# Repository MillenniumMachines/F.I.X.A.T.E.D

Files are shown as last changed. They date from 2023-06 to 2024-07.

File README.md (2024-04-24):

# millenium machines F.I.X.A.T.E.D

Welcome to the Millenium machines fixated project. Fixated is a list of fixtures and parts created for the Milo line of machines.

## FIXATED fixture plates  

- The FIXATED full monty

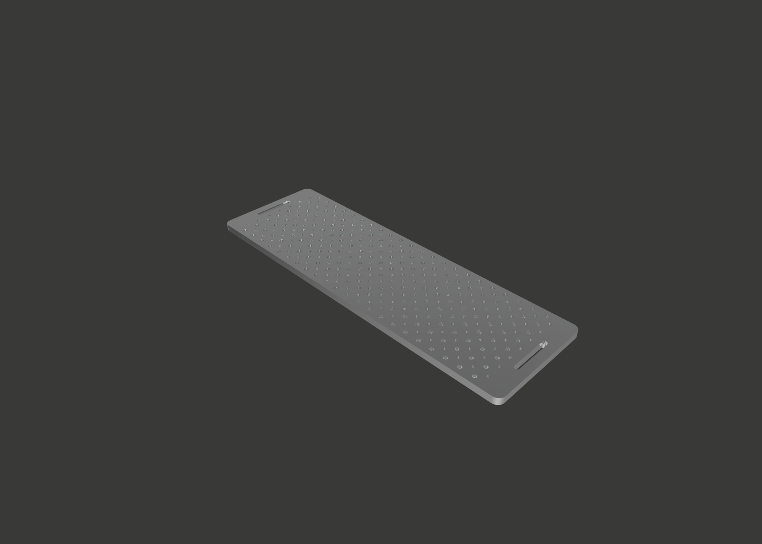
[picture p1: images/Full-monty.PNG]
The FIXATED full monty


A fixture plate system designed to fit the bed of a standard sized milo V1.5 (500x160mm) and features 
hole spacings of 20mm on center intended for tapping to M5 and another set of holes also 20mm on center to accomadate M6 dowels.

- The FIXATED full monty (SLIM)

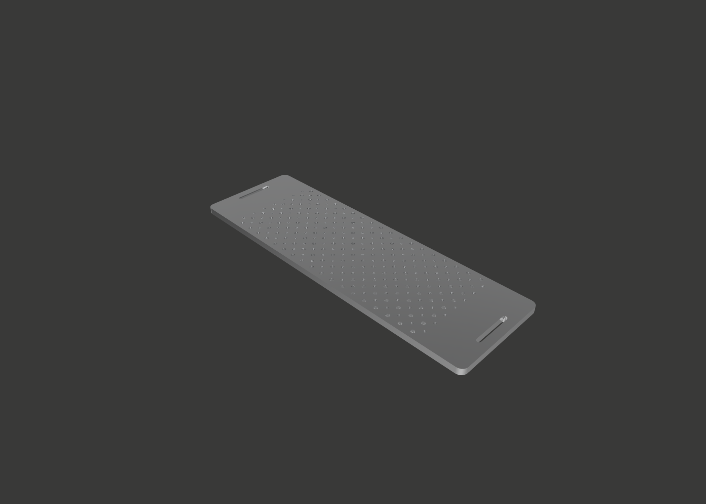
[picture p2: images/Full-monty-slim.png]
The FIXATED full monty slim


The full monty slim covers the same features as the regular full monty but only covers the workable area of a standard milo v1.5.

- The FIXATED continental breakfast 

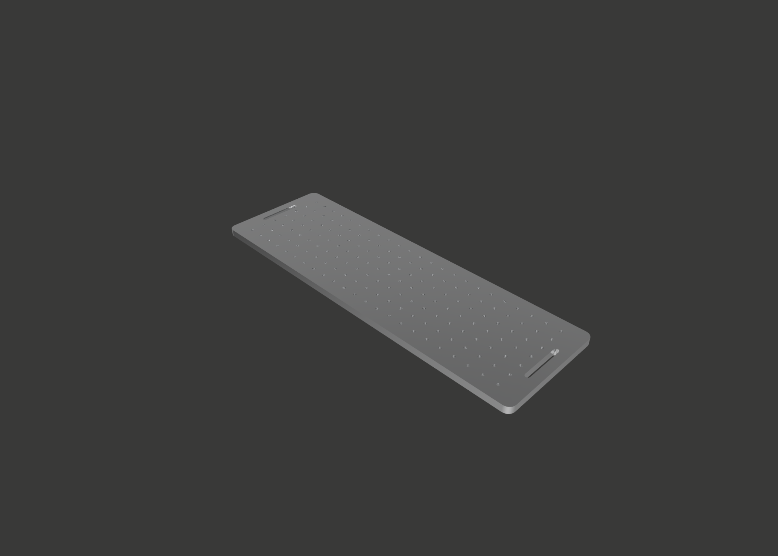
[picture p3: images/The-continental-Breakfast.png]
The FIXATED Continental breakfast


The full monty's slim european cousin this fixture plate system designed to fit the bed of a standard sized milo V1.5 (500x160mm) and features hole spacings of 20mm on center intended for tapping to M5 unlike the full monty it does not include the holes for the M6 dowels.

- The FIXATED continental breakfast (SLIM)

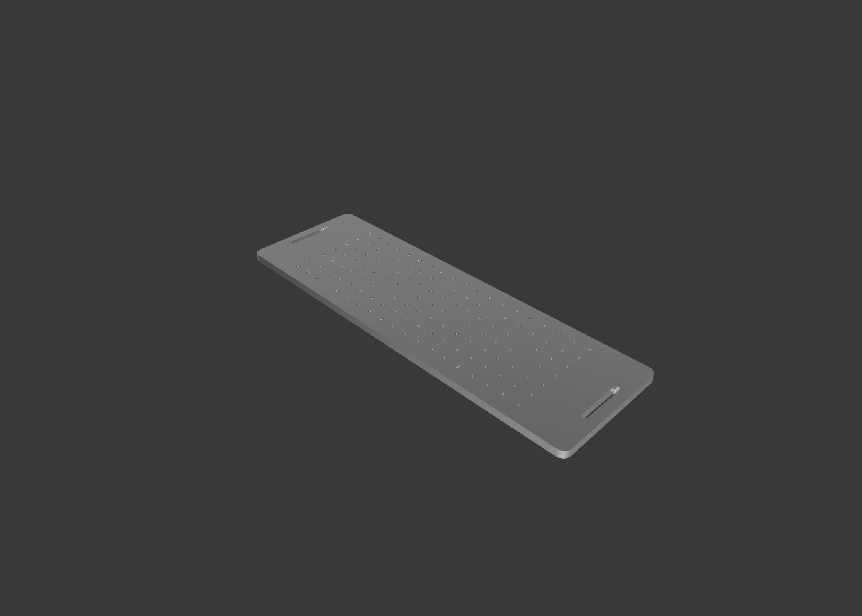
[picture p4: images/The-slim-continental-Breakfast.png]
The FIXATED Continental breakfast


The continental breakfast slim covers the same features as the regular continental breakfast but only covers the workable area of a standard milo v1.5.

For manufacturing specifications and technical drawings please see [documentation](docs/README.md).

## FIXATED Plate Clamps

The optimal way to hold your fixated plate down is to utilise these plate clamps. They can be 3d printed but for the best performance you will want to machine a set.

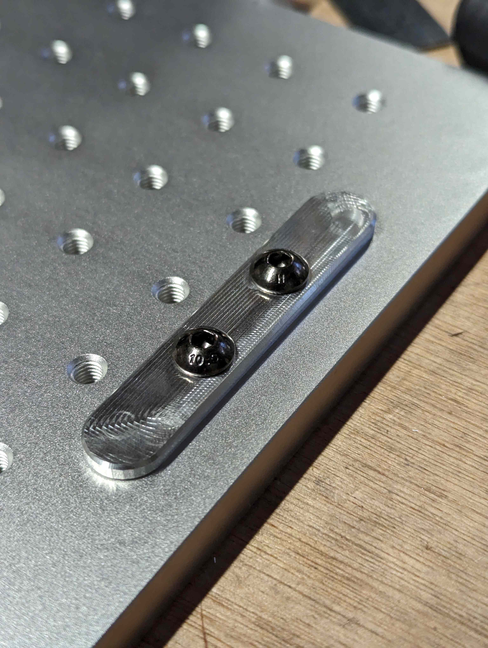
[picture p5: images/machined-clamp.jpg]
FIXATED machined plate clamp


For manufacturing specifications and technical drawings please see [documentation](/docs/Machined%20plate%20clamps/README.md).

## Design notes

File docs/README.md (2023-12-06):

# millenium machines F.I.X.A.T.E.D documetation 

Welcome to fixated Docs here you'll find documentation related to the manufacture and technical specifications of all our fixtures, these specifications are only a guideline and can be modified to meet your requirements.  

##  DOCUMENTATION

### - All Fixated fixture plates 

MATERIAL           : Cast tooling plate, MIC6 or aluminium 6061/6068 that has been milled flat

PROCESS            : Laser Cut Or CNC milled 

GENERAL TOLERANCES FOR PRE-TAPPED AND PRE-REAMED PARTS: 

                     - Standard fit tolerances for all 4.2mm holes to be tapped later to M5

                     - Standard fit tolerances for all 5.8mm holes to be reamed later to M6 (full monty only)
                     
                     - Perimeter tolerance of -0.05mm +0mm 
                     
                     - Perimeter parralelism tolerance of 0.05mm acrross the 2 longest sides
                     
                     - No given tolerance for parralelism of top and bottom faces
                     
                     - Flatness tolerance of top and bottom 0.05mm across length and width of part
                   
NOTES: These plates are intended to be laser cut or milled as blanks, all holes have been sized to tapped and reamed by the end user to reduce costs. Full monty and full monty slim may cause issues with material stress release during manufacture which can lead to part warping if you do not need the use of the M6 dowel feature consider using the continental breakfast variants instead. If you require the tolerances for a tapped and reamed plate you can find the tolerances below.

GENERAL TOLERANCES FOR TAPPED AND REAMED PARTS: 

                     - M5 threaded holes (H6)

                     - M6 Dowel holes (H7) (full monty only)
                     
                     - Perimeter tolerance of -0.05mm +0mm 
                     
                     - Perimeter parralelism tolerance of 0.05mm acrross the 2 longest sides
                     
                     - No given tolerance for parralelism of top and bottom faces
                     
                     - Flatness tolerance of top and bottom 0.05mm across length and width of part

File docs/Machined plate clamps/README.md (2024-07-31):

# Millennium Machines F.I.X.A.T.E.D Machined Plate Clamps Documentation 

This page contains the information required to machine your own FIXATED plate clamps. This is considered an ideal first project as it utilises low cost small pieces of stock material, a few simple setups and only 3 different end mills.

##  DOCUMENTATION

CAD :
- [STEP file](/CAD/Fixture%20Plates/Machined%20plate%20clamps/Fixated%20clamp.step)
- [f3d file including CAM operations](/CAD/Fixture%20Plates/Machined%20plate%20clamps/Fixated%20clamp.f3d)
- [Fusion tool library](/CAD/Fixture%20Plates/Machined%20plate%20clamps/Fixated%20clamp%20LDO%20tool%20library.tools)

MATERIAL           : Bar stock, aluminium 6061/6068

BOM                :                

- 2x 20x15x70mm Aluminium 6082T6 Flat Bar
- 4x M5 x 10mm Form A Flat Washers (DIN 125) - Stainless Steel (A2)
- 4x M5 x 18mm Socket Button Screws (ISO 7380-1) - Stainless Steel (A2)
- 4x Roll in Spring Loaded T Nut M5 for 20x20 20 Series Aluminium Extrusions

Tooling :

- End Mill, Single Flute, 6x22mm, Carbide, DLC Coating
- End Mill, Single Flute, 3x12mm, Carbide, DLC Coating
- Chamfer Mill, Three Flute, 90°, 6mm, Carbide, DLC Coating

PROCESS            : Milled on Milo 

RESOURCES          : 

- [Setup sheet 1](/docs/Machined%20plate%20clamps/Fixated%20clamp%20setup%201.pdf)
- [Setup sheet 2](/docs/Machined%20plate%20clamps/Fixated%20clamp%20setup%202.pdf)
- [Setup sheet 3](/docs/Machined%20plate%20clamps/Fixated%20clamp%20setup%203.pdf)
- [video guide by 3DPandME](https://www.youtube.com/live/bzlwI8ah9Cs?si=_gUOolzj2h1DFucY)

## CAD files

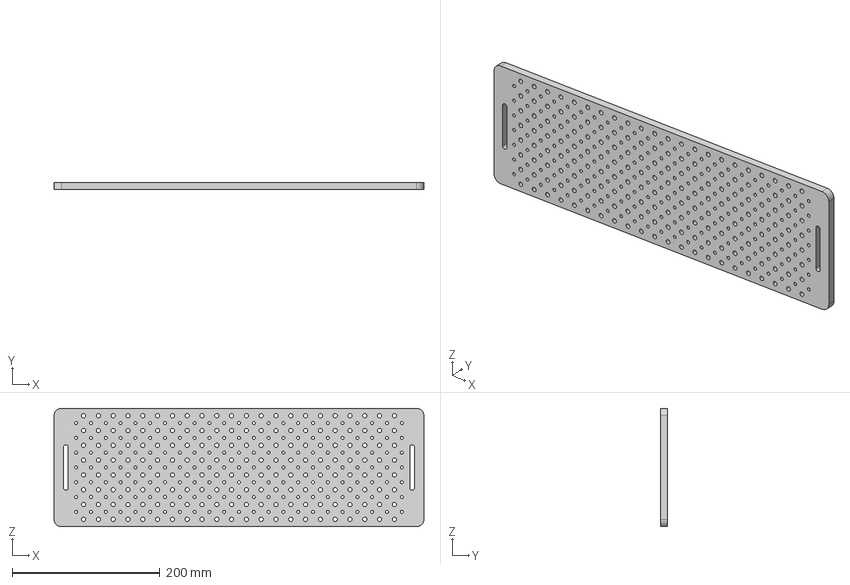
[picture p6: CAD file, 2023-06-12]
CAD/Fixture Plates/The Full monty/Full-Monty-Fixture-Plate.step
500.0 x 10.0 x 160.0 mm

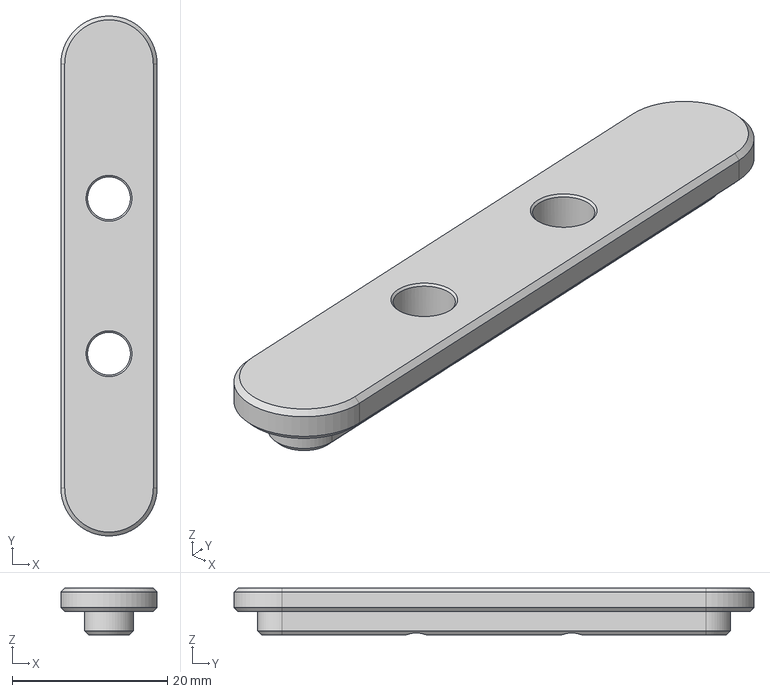
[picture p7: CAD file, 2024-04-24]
CAD/Fixture Plates/Machined plate clamps/Fixated clamp.step
12.4 x 66.9 x 6.00 mm

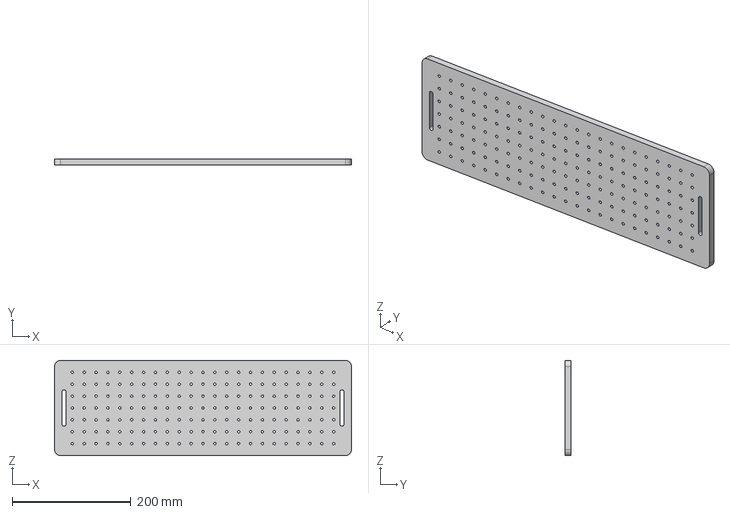
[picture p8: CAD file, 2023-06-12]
CAD/Fixture Plates/The continental breakfast/The-continental-Breakfast.step
500.0 x 10.0 x 160.0 mm

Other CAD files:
CAD/Fixture Plates/The Full monty/Full-Monty-slim-fixture-plate.step
CAD/Fixture Plates/The continental breakfast/The-slim-continental-Breakfast.step
CAD/Fixture Plates/Machined plate clamps/Fixated clamp.f3d

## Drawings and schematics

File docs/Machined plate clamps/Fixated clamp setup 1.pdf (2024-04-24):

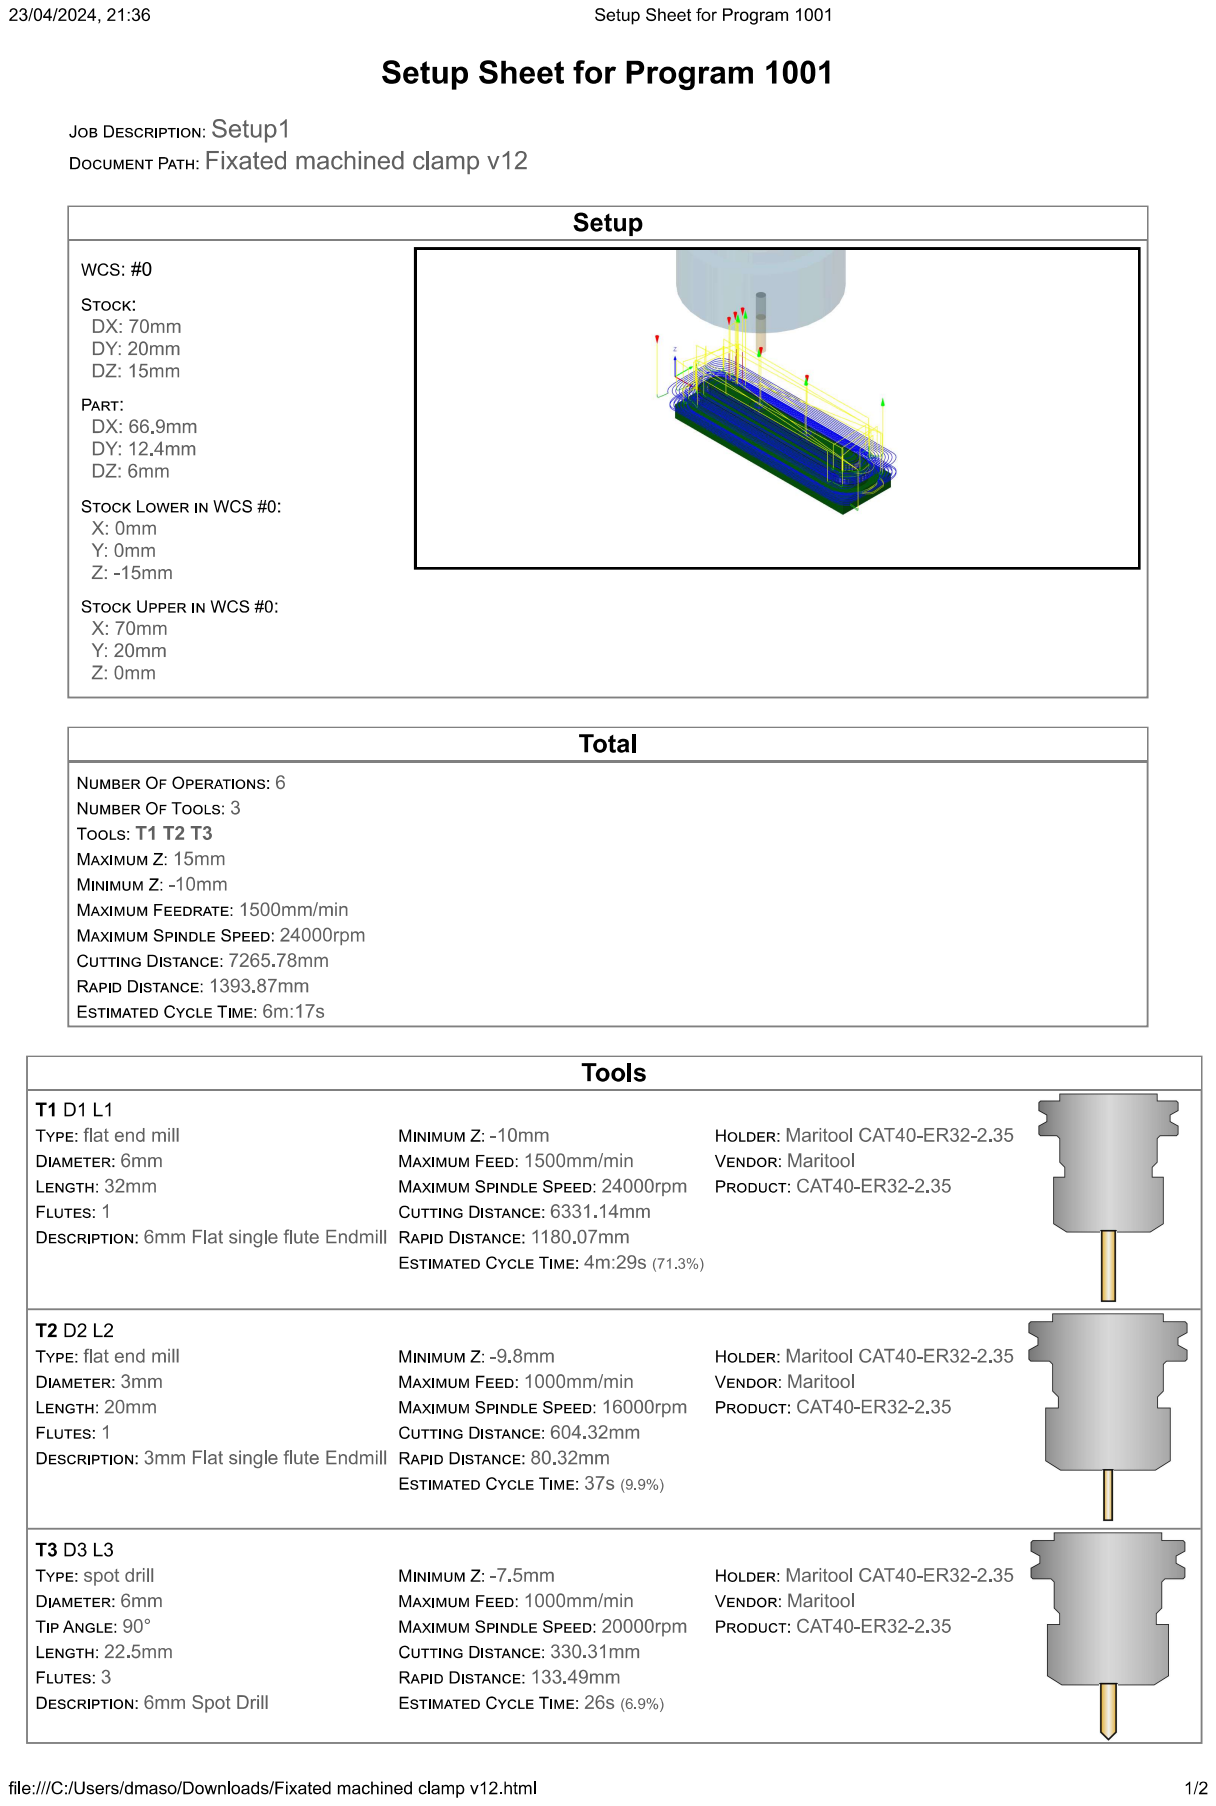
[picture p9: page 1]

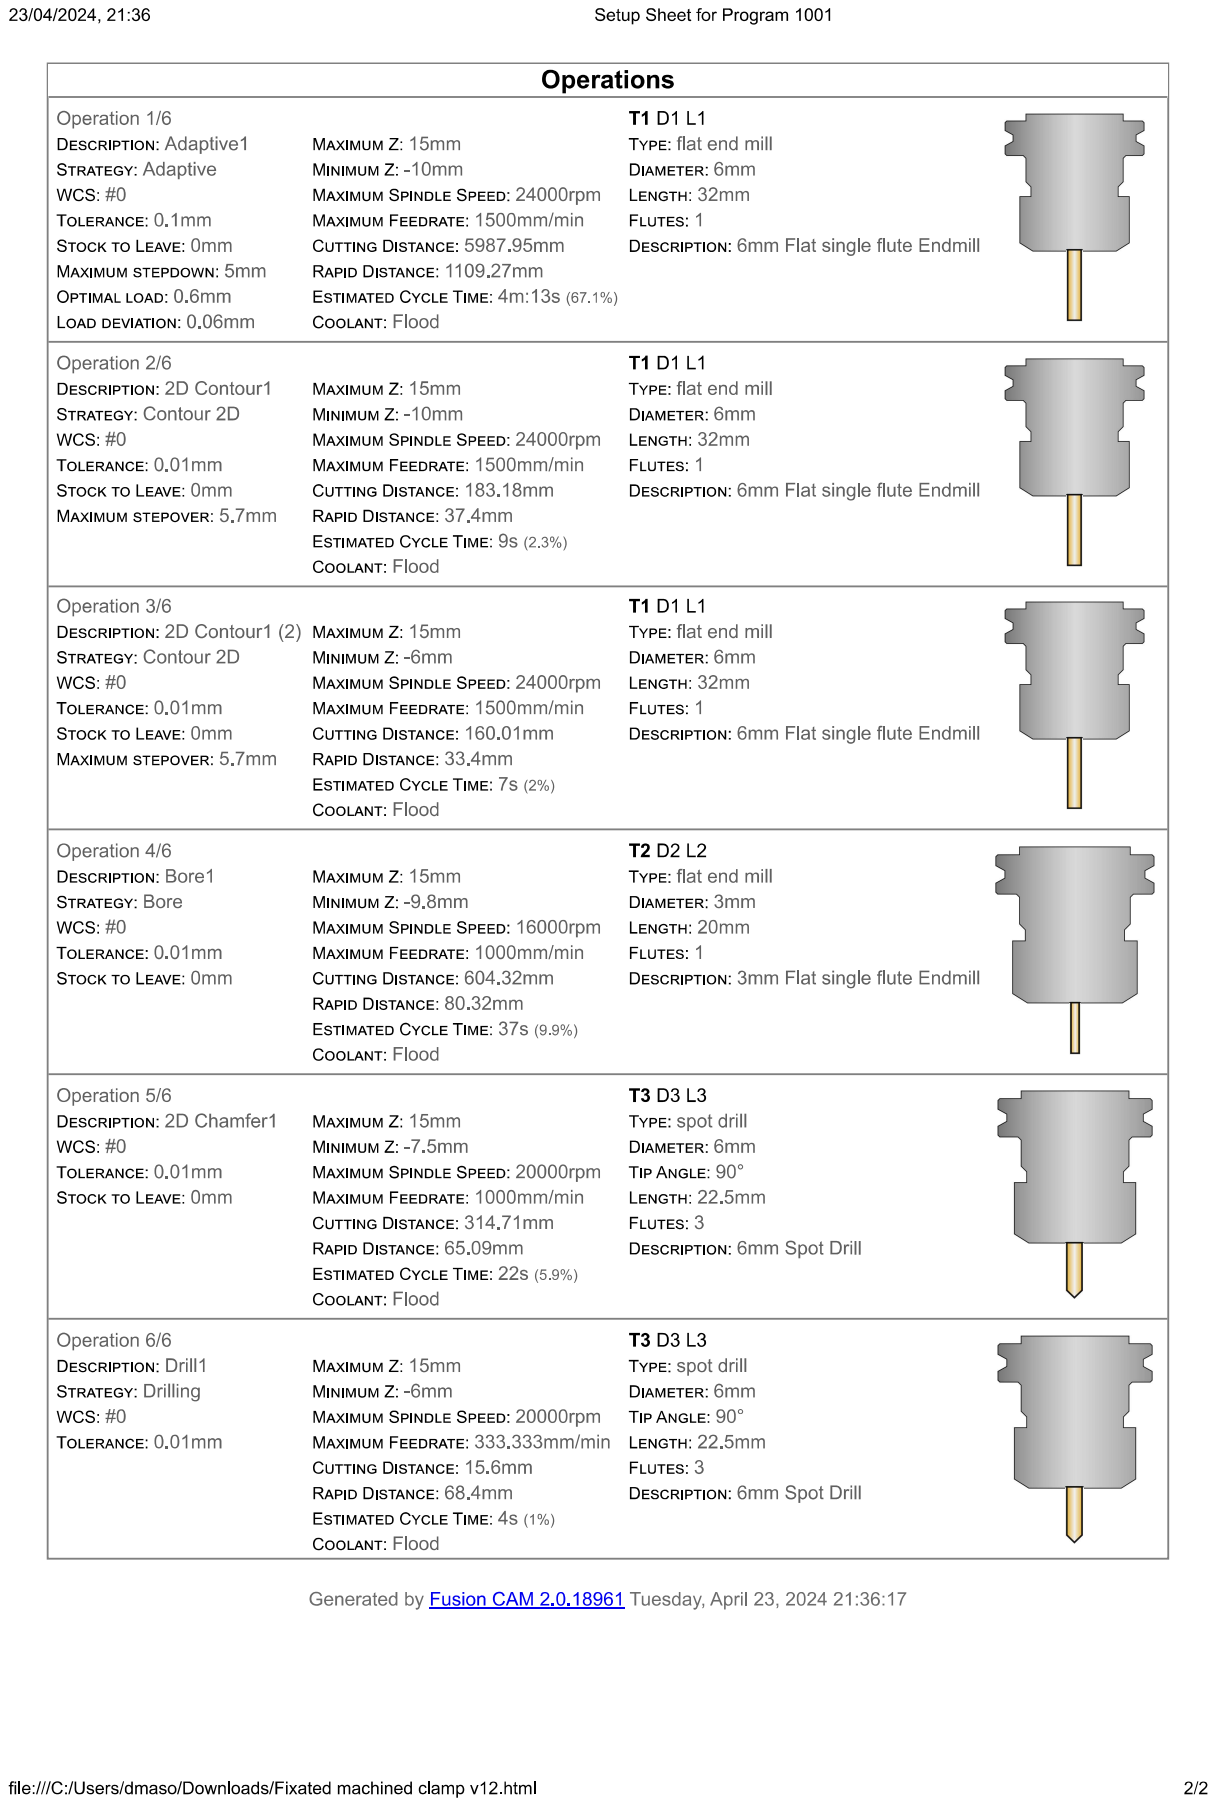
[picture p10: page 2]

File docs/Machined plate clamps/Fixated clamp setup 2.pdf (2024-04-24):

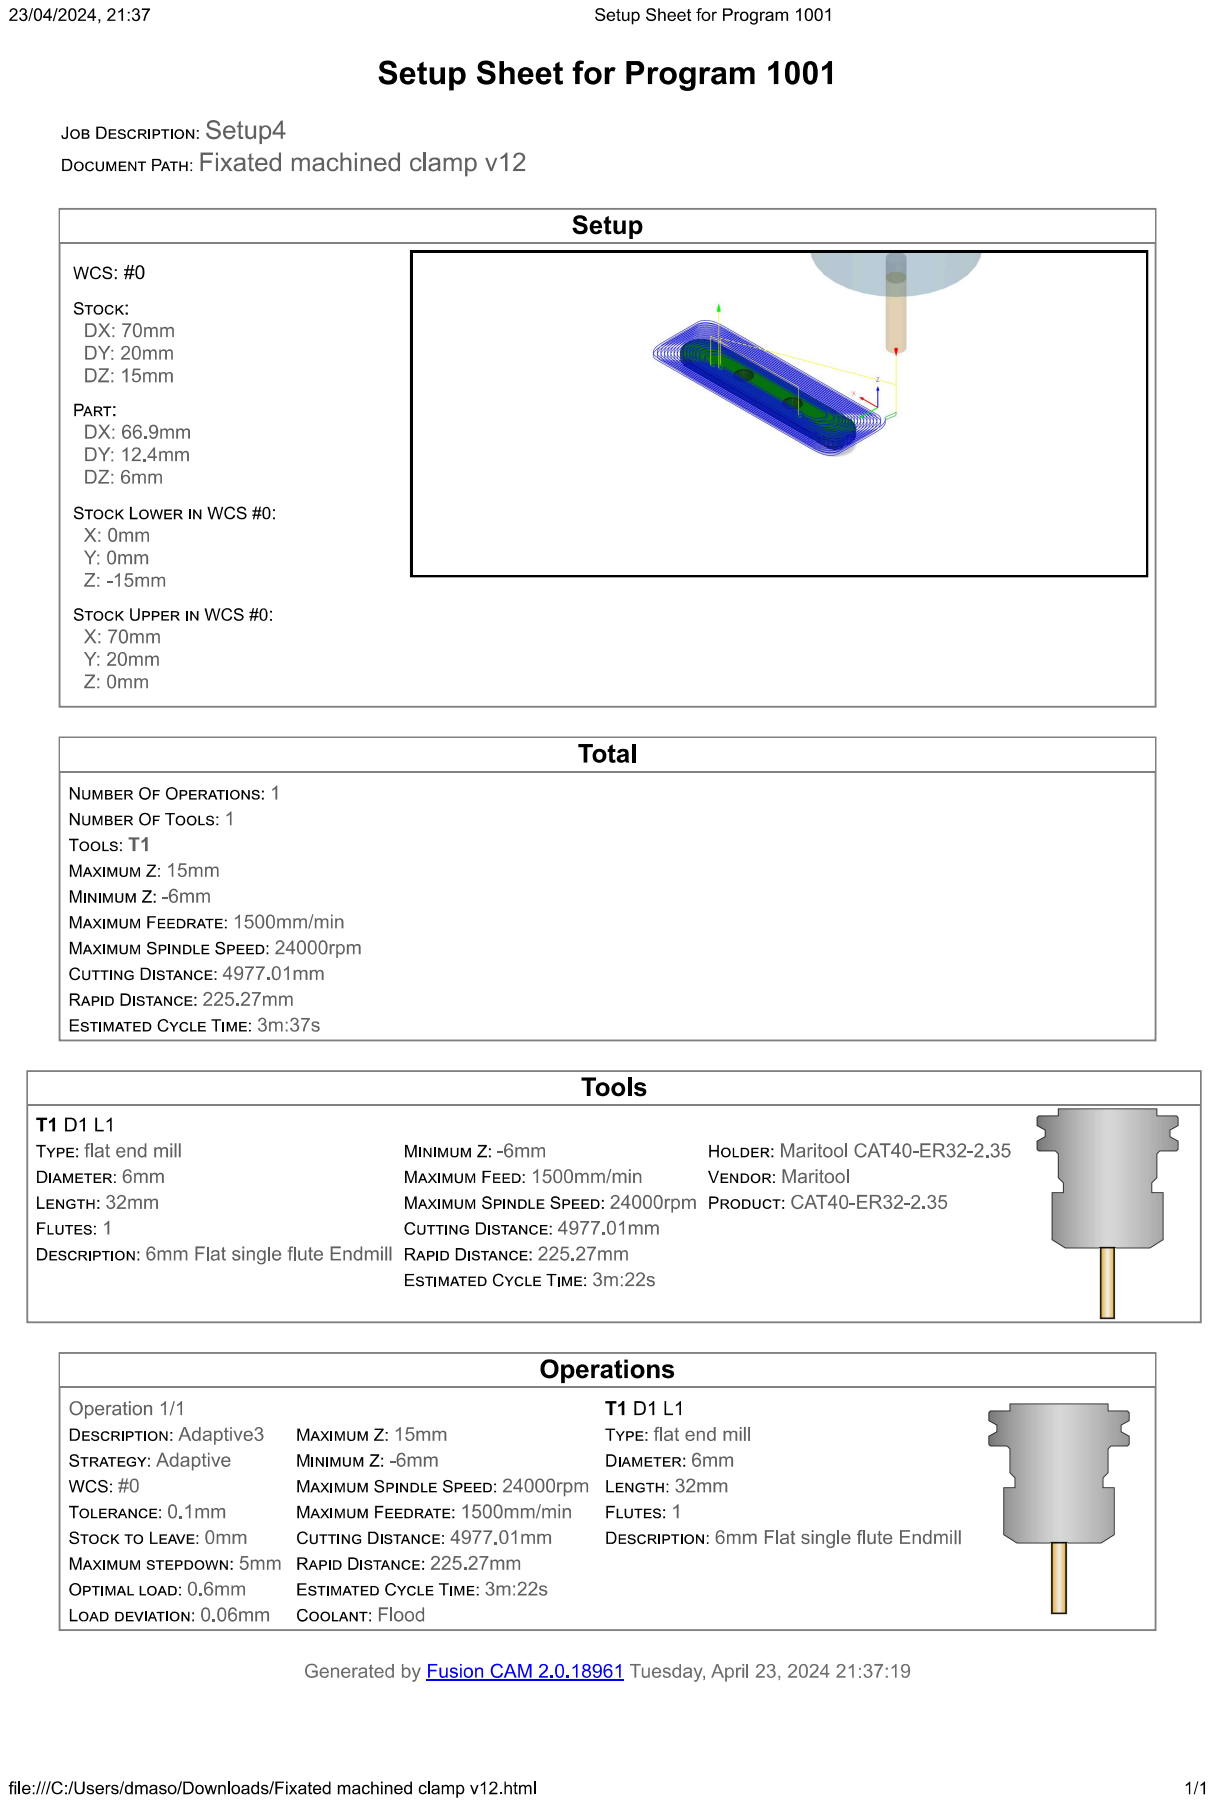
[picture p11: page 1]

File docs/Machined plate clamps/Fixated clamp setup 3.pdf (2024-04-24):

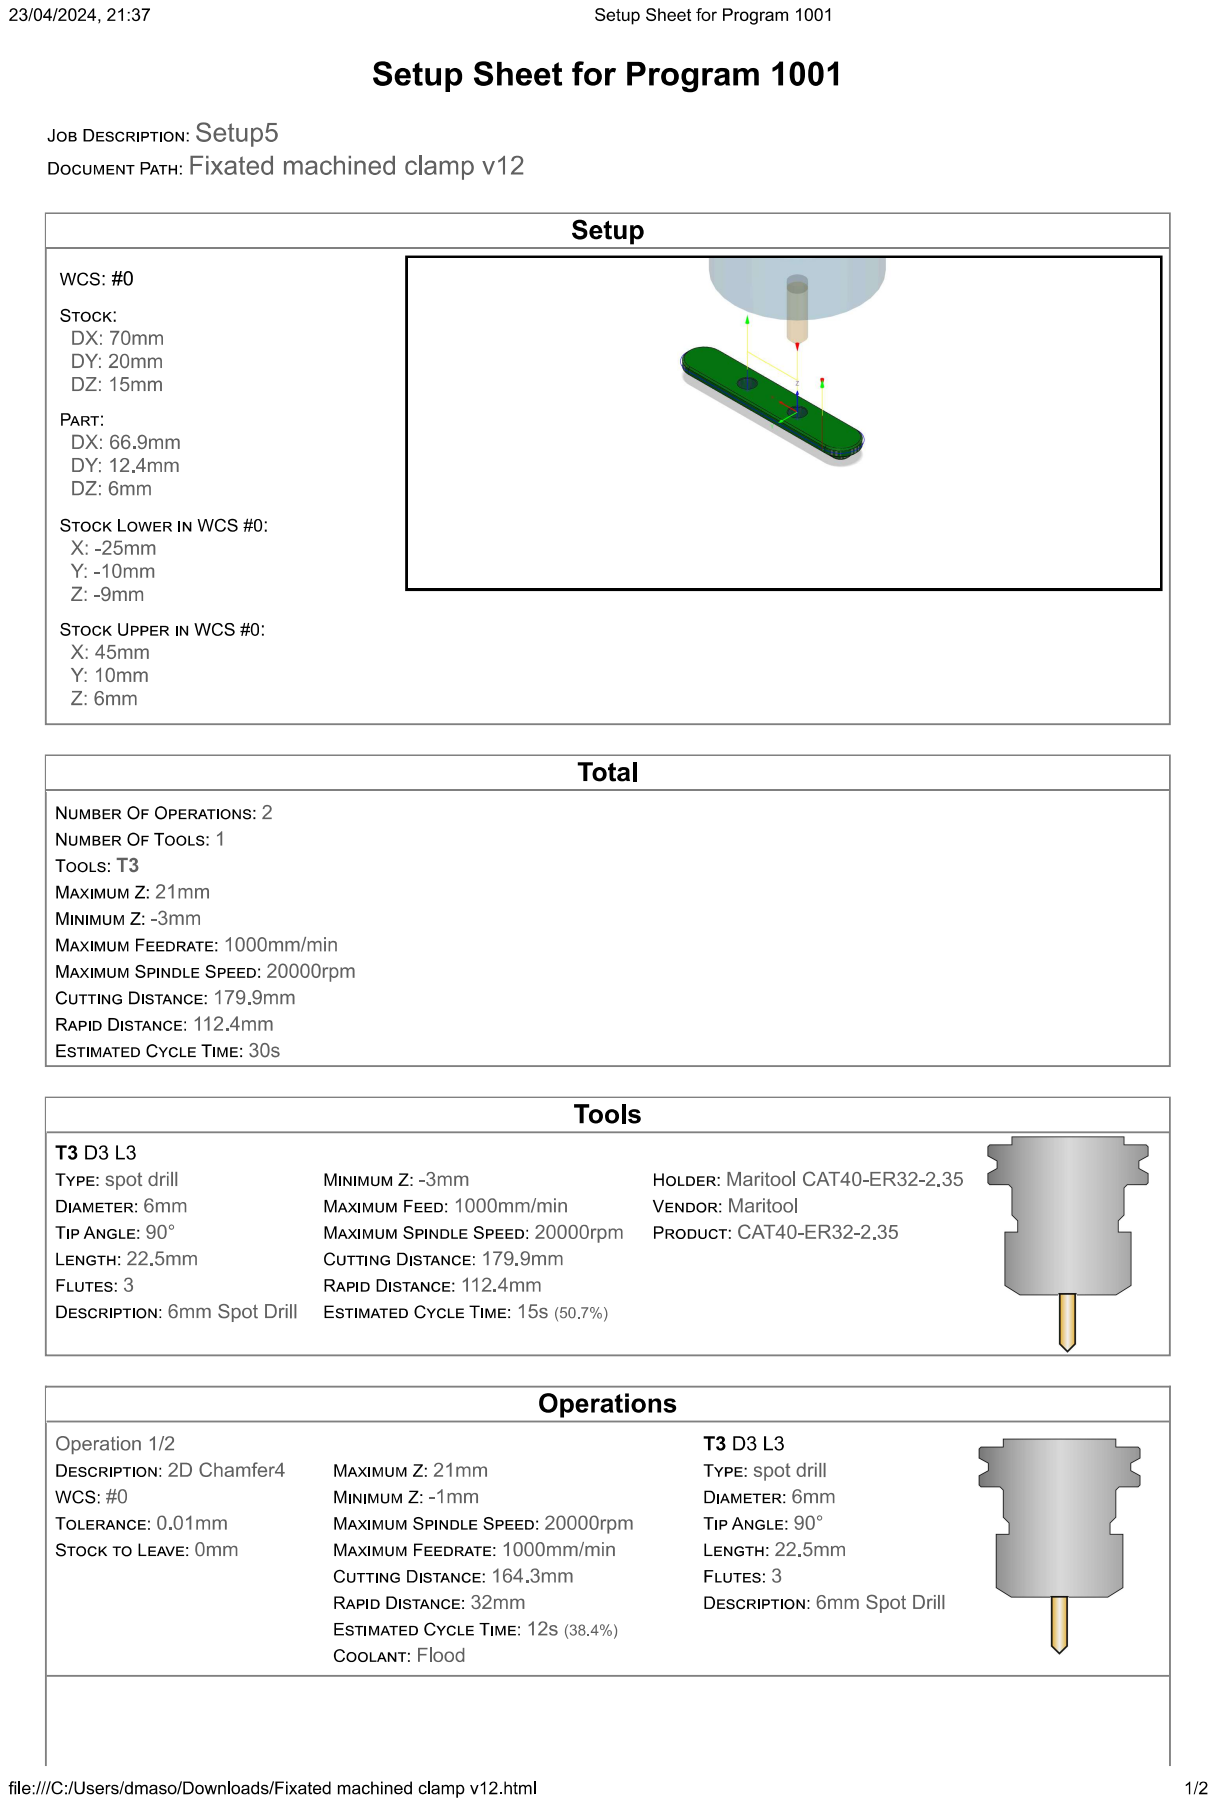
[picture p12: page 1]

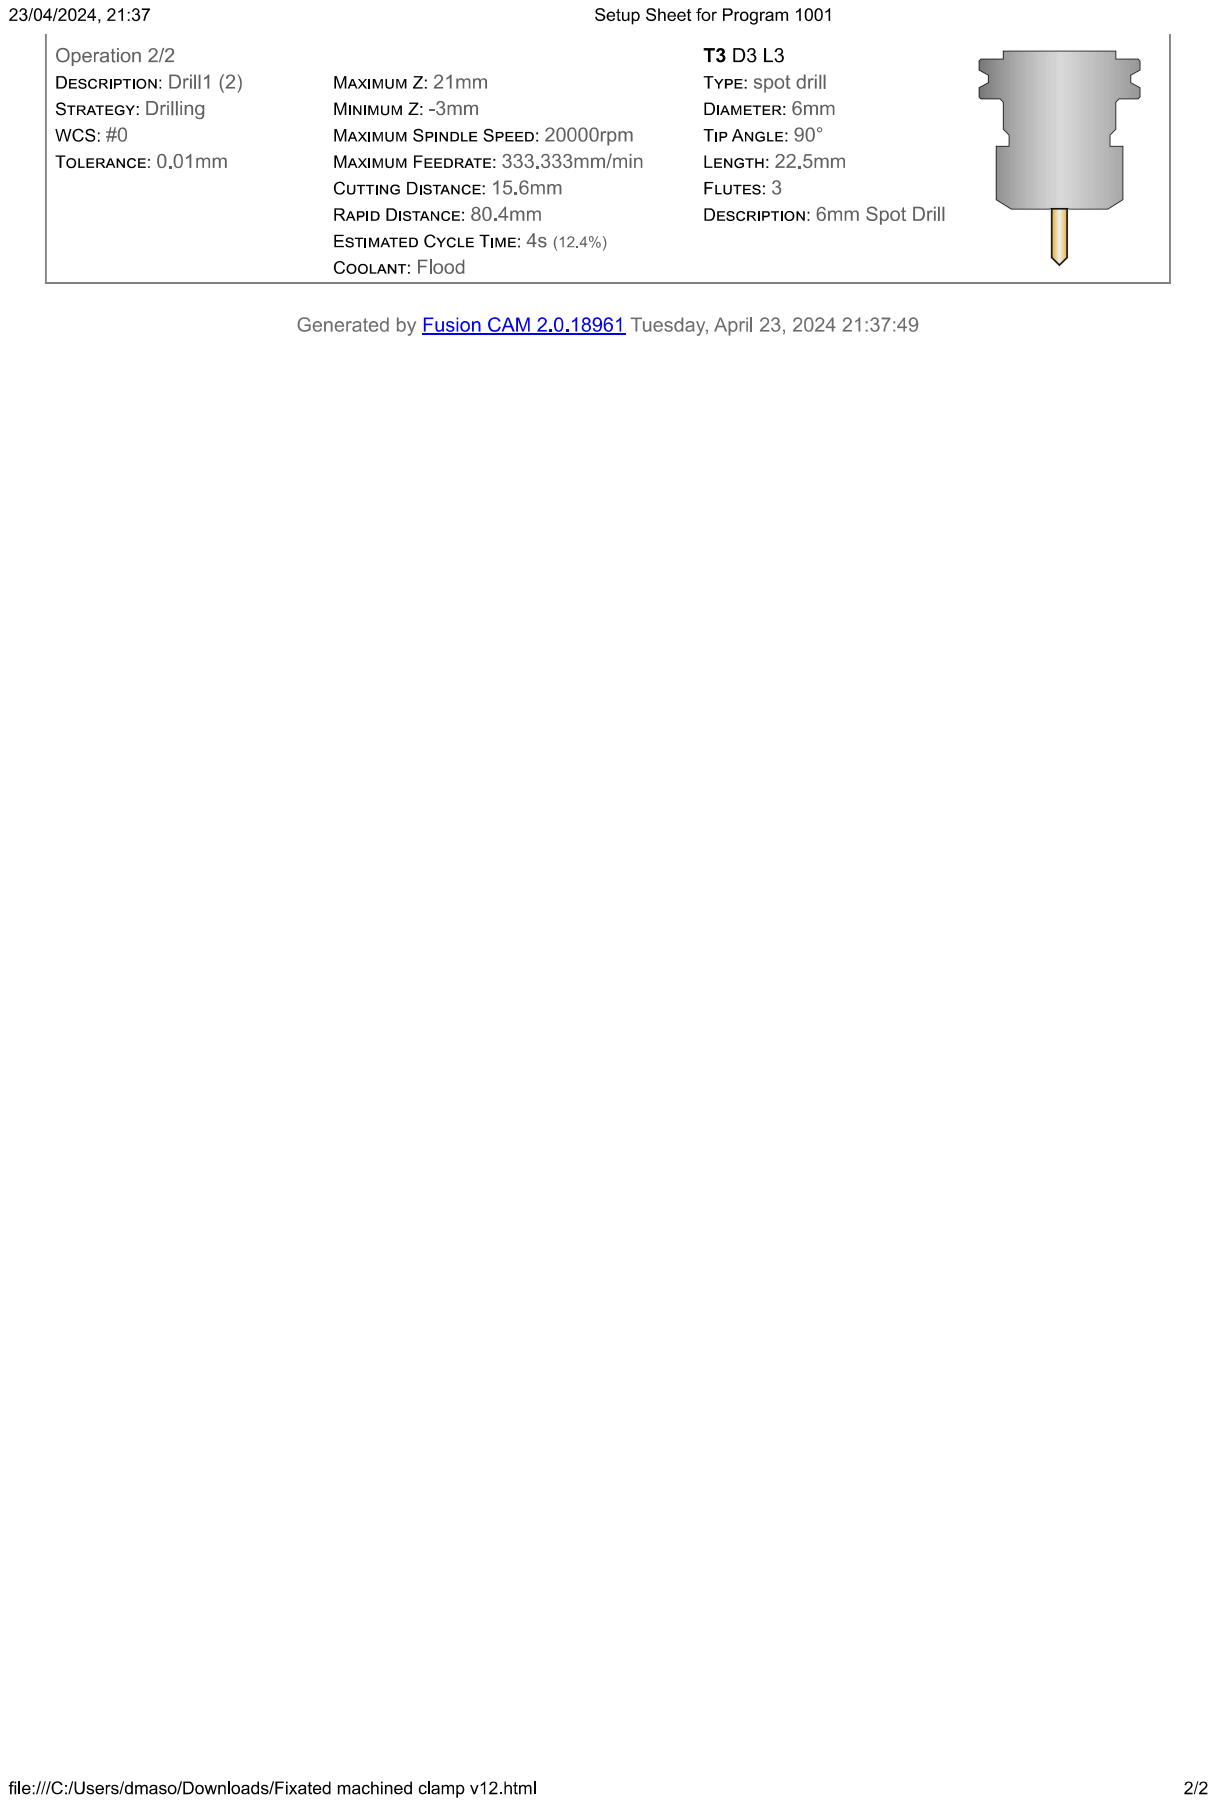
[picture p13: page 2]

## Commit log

2023-06-12 Added fixture plate CAD
    [Full-Monty-Fixture-Plate v2.step, Full-Monty-slim-fixture-plate v1.step, The-continental-Breakfast v1.step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]
2023-06-12 Added images of fixture plates
2023-06-12 Added fixture plate .svg files
2023-11-24 Consistent renaming to match other repos
    The usual changes:
    - Capitalisation, spacing, removing redundancy
    - Changed formatting of readme and docs for consistency
    - Modified 'M6 dowels' to '6mm dowels'
    [Full Monty Fixture Plate slim.step, Full Monty Fixture Plate.step, The Continental Breakfast Fixture Plate slim.step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]
2023-12-06 Added reamed and tapped versions of the fixture plates
    [Full-Monty-Fixture-Plate v2.step, Full-Monty-Fixture-Plate.step, Full-Monty-slim-fixture-plate v1.step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]
2024-04-23 Fixes formatting error on BOM line
2026-11-08 Fix spelling and version in README
    Corrected spelling of 'Millenium' to 'Millennium' and updated version to 'v1.5'.
